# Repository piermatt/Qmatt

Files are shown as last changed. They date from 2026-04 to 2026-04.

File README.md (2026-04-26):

# Low-Cost Arduino-Based ODMR System for NV Centers in Diamond




A fully open-source, low-cost Optically Detected Magnetic Resonance (ODMR)
spectrometer targeting nitrogen-vacancy (NV⁻) centers in diamond, built around
the **Seeeduino XIAO ESP32-C3** microcontroller and the **ADF4351** wideband
PLL synthesizer.

---

## Repository Structure

```
odmr_nv_repo/
├── hardware/
│   ├── schematic/          # KiCad schematic (.kicad_sch, .pdf)
│   ├── gerber/             # PCB Gerber files for fabrication
│   └── 3d_parts/           # STL files for 3-D printed optomechanics
├── software/
│   ├── firmware/           # Arduino (.ino) firmware for ESP32-C3
│   └── analysis/           # Python scripts for data processing & plotting
├── references/             # Key literature (DOI list + BibTeX)
├── results/
│   └── sample_data/        # Example sweep CSV outputs
├── BOM.csv                 # Bill of Materials with estimated costs
└── README.md
```

---

## Operating Principle

1. A **532 nm CW laser** (5 mW) illuminates
   the diamond sample, polarising NV spins into the ms = 0 ground state.
2. Microwave radiation from the **ADF4351** (2850 – 2890 MHz) is swept across
   the NV zero-field splitting (~2870 MHz).
3. At resonance, spin population is transferred to ms = ±1, reducing
   photoluminescence — the **ODMR dip**.
4. A photodiode + **TL082 op-amp** transimpedance/buffer stage converts
   PL intensity to voltage; the ESP32-C3 ADC samples differentially (MW ON vs OFF)
   to extract contrast and reject common-mode noise.

---

## Quick Start

### Hardware
1. Fabricate the PCB from `hardware/gerber/` (e.g. JLCPCB / PCBWay, 2-layer).
2. Assemble components following `hardware/schematic/odmr_schematic.pdf` and `BOM.csv`.
3. Print `hardware/3d_parts/` STL files (PLA, 0.2 mm layer, 20% infill).
4. Mount: laser → ND filter holder → diamond stage → 550 nm longpass filter → photodiode.

## Experimental Setup

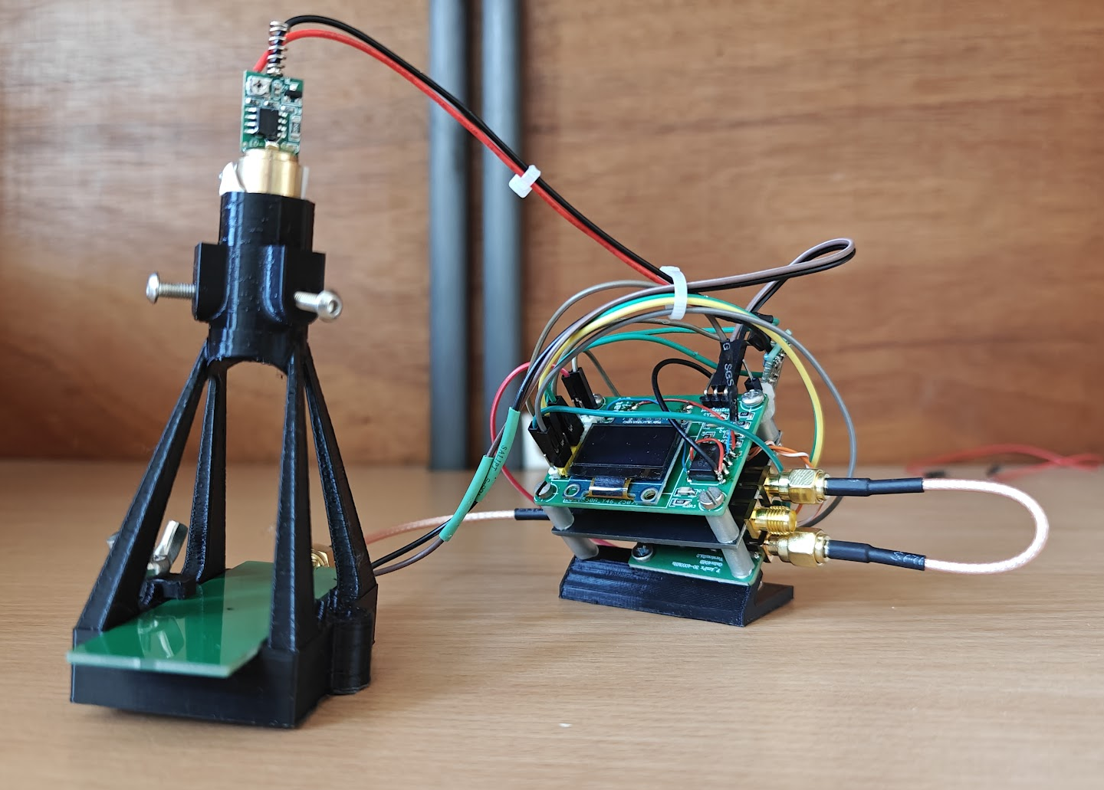
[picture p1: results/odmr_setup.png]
DIY ODMR Setup


Figure: Compact, low-cost ODMR system integrating:
- ADF4351 microwave source
- 0.1-2000MHz Broadband RF Amplifiers
- ESP32-C3 control and acquisition board
- Photodiode detection
- 3D-printed optomechanical mount

The system is designed for alignment simplicity and minimal footprint while maintaining sufficient stability for ODMR measurements.

### Firmware
1. Install **Arduino IDE ≥ 2.x** + ESP32 board support (`esp32` by Espressif, ≥ 3.x).
2. Open `software/firmware/odmr_firmware.ino`.
3. Select board: **XIAO_ESP32C3** — Flash 4 MB, no PSRAM.
4. Upload and open Serial Monitor at **115200 baud**.
5. Send:
   - `S` — full run (survey + differential sweep)
   - `V` — survey scan only
   - `D` — differential ODMR only
   - `X` — abort current scan

## Example ODMR Spectrum

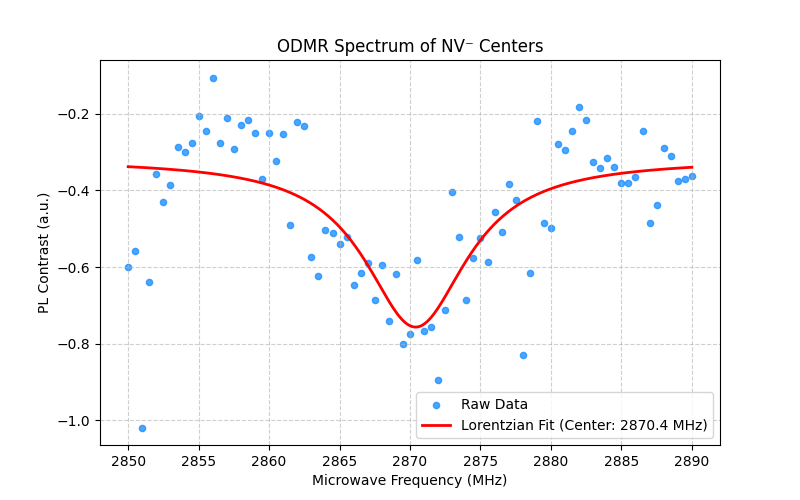
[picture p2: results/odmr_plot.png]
ODMR Spectrum


*Figure: Optically Detected Magnetic Resonance (ODMR) spectrum of NV⁻ centers in diamond.*

A clear fluorescence dip is observed near the zero-field splitting (~2870 MHz), corresponding to the ms = 0 → ms = ±1 transition. The contrast arises from spin-dependent intersystem crossing, which reduces photoluminescence at resonance.

**Key observations:**
- Broad dip centered around **~2870–2872 MHz**, aligning excellently with the theoretical ZFS without significant calibration offset.
- Signal-to-noise is sufficient for low-cost hardware to properly resolve the resonance curve.
- Demonstrates feasibility of differential acquisition using MW ON/OFF modulation.

## Sweep Parameters (default firmware)

| Parameter | Value | Notes |
|---|---|---|
| Frequency start | 2850 MHz | Below NV ZFS |
| Frequency stop | 2890 MHz | Above NV ZFS |
| Step size | 0.5 MHz | 500 kHz resolution |
| Averages / step | 8 ON/OFF pairs| ~50 s total sweep |
| ADC integration | 20 ms | 50 Hz rejection (64-sample window) |
| RF settle time | 5 ms | Safe PLL lock margin |

---

## License

MIT License — see [LICENSE](LICENSE).

## Citation

If you use this system in published work, please cite:

> Mattia Pierpaoli. *Low-Cost Arduino ODMR for NV Centers in Diamond*. GitHub, 2026.
> https://github.com/piermatt/Qmatt

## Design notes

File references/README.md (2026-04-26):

# Key References — DOI List

| # | Authors | Title (short) | Journal / Source | Year | DOI |
|---|---|---|---|---|---|
| 1 | Gruber et al. | ODMR on single NV defect centers | Science | 1997 | 10.1126/science.276.5321.2012 |
| 2 | Doherty et al. | The NV colour centre in diamond (review) | Physics Reports | 2013 | 10.1016/j.physrep.2013.02.001 |
| 3 | Rondin et al. | Magnetometry with NV defects (review) | Rep. Prog. Phys. | 2014 | 10.1088/0034-4885/77/5/056503 |
| 4 | Barry et al. | Sensitivity optimization for NV magnetometry (review) | Rev. Mod. Phys. | 2020 | 10.1103/RevModPhys.92.015004 |
| 5 | Clevenson et al. | Broadband magnetometry with diamond waveguide | Nature Physics | 2015 | 10.1038/nphys3291 |
| 6 | Schloss et al. | Simultaneous broadband vector magnetometry | Phys. Rev. Applied | 2018 | 10.1103/PhysRevApplied.10.034044 |
| 7 | Webb et al. | Nanotesla sensitivity compact NV magnetometer | Appl. Phys. Lett. | 2021 | 10.1063/1.5095241 |
| 8 | Chipaux et al. | Magnetic imaging with NV ensemble | Eur. Phys. J. D | 2015 | 10.1140/epjd/e2015-60080-y |
| 9 | Analog Devices | ADF4351 datasheet | Datasheet | 2021 | analog.com/ADF4351 |
|10 | Seeed Studio | XIAO ESP32-C3 Getting Started | Documentation | 2023 | wiki.seeedstudio.com/XIAO_ESP32C3 |

## Reading Guide

**Start here (foundations):**
- Refs 2 & 3: Complete reviews of NV physics and magnetometry — essential reading.
- Ref 4 (Barry 2020): Definitive guide to sensitivity, noise sources, and ODMR modes.

**Low-cost / practical implementations:**
- Ref 7 (Webb 2021): Compact diamond NV magnetometer — closest to this project's spirit.
- Ref 5 (Clevenson 2015): Light-trapping geometry for sensitivity enhancement.

**Hardware datasheets:**
- Refs 9 & 10: ADF4351 PLL and ESP32-C3 microcontroller.

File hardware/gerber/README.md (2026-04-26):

# Gerber Files — ODMR PCB v1.0

## Ordering (JLCPCB example)
1. Zip all files in this folder → upload to jlcpcb.com
2. Select: 2-layer, FR4, 1.6 mm, HASL, green, qty 5
3. Estimated cost: ~$2 USD per board (min order 5 pcs)

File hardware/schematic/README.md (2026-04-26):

# Schematic

## Design Notes

### Signal Chain
```
532 nm laser  ──(gate: Q1/2N2222A)──►  Diamond sample
                                              │ PL (>550 nm)
                                              ▼
                                        BPW34 photodiode
                                              │ photocurrent
                                              ▼
                                   TL082 U1.1 — transimpedance amp
                                   R_f = 1 MΩ, C_f = 10 pF
                                              │ voltage
                                              ▼
                                   TL082 U1.2 — unity buffer
                                   Virtual GND: R1=R2=1kΩ → VIRTUAL_GND=2.5V
                                              │
                                              ▼
                                   ESP32-C3 ADC (GPIO3, 12-bit, Vref=3.3V)
```

### Microwave Path
```
ADF4351 module
  CLK  → ESP32-C3 GPIO8  (SPI SCK)
  DATA → ESP32-C3 GPIO10 (SPI MOSI)
  LE   → ESP32-C3 GPIO7
  CE   → 3.3 V (always enabled)
  RF_OUT → SMA J2 → coaxial → Cu microwave loop near diamond
```

### Laser Gate
```
ESP32-C3 GPIO2 → 10 kΩ → Q1 base
Q1 collector → laser module VCC (3–5V)
Q1 emitter  → GND
```

### Power
- USB-C 5 V from PC or power bank → XIAO onboard 3.3 V LDO
- ADF4351 module powered from 5 V USB line
- Laser module powered from 5 V through Q1

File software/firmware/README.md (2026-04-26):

# Firmware — odmr_firmware.ino

## Target Platform
- **Board**: Seeeduino XIAO ESP32-C3
- **Arduino IDE**: ≥ 2.x with esp32 board support ≥ 3.x
- **Board package**: `esp32` by Espressif Systems

## Installation
1. In Arduino IDE → Boards Manager → search "esp32" → install Espressif esp32
2. Select: **Tools → Board → XIAO_ESP32C3**
3. Tools → Flash Size: **4MB (No OTA)**
4. Upload `odmr_firmware.ino`

## Serial Commands (115200 baud)
| Command | Action |
|---|---|
| `S` | Survey scan then differential sweep |
| `V` | Survey scan only |
| `D` | Differential sweep only |
| `X` | Abort current scan mid-sweep |

## Output Format — Survey
```
# SURVEY_START
# Freq_MHz, ADC_Sum
2850.00, 87234
2850.50, 87190
...
# SURVEY_END
```

## Output Format — Differential Sweep
```
# ODMR_SWEEP_START
# Freq_MHz, OFF_sum, ON_sum, Contrast_%
2850.00, 698876, 698712, 0.0235
...
# ODMR_SWEEP_END
```

## Tuning Parameters
Edit these `#define` lines in the firmware:

| Define | Default | Description |
|---|---|---|
| `FREQ_START_MHZ` | 2850.0 | Sweep start frequency (MHz)  |
| `FREQ_STOP_MHZ` | 2890.0 | Sweep stop frequency (MHz) |
| `FREQ_STEP_MHZ` | 0.5 | Step size (MHz) |
| `DIFFERENTIAL_AVG` | 8 | ON/OFF averages per step |
| `SETTLE_US` | 5000 | RF settle time (µs) |
| `ADF_POWER` | 3 (+5dBm) | ADF4351 output power 0–3 |

## Dependencies
- Built-in `SPI.h` only — no external libraries required.

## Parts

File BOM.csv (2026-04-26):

# | Reference | Description | Value / Part Number | Quantity | Unit Price (EUR) | Total (EUR) | Supplier / Notes
1 | U_MCU | Microcontroller | Seeeduino XIAO ESP32-C3 | 1 | 5.5 | 5.5 | Seeed Studio / AliExpress
2 | U_PLL | Wideband PLL Synthesizer | ADF4351 module (25 MHz TCXO on-board) | 1 | 8 | 8 | AliExpress (bare module)
3 | U1 | Dual JFET Op-Amp | TL082CP (DIP-8) | 1 | 0.4 | 0.4 | LCSC / Mouser
4 | LD1 | Green DPSS Laser Module | 532 nm / 5 mW CW / 3–5 V TTL gate | 1 | 12 | 12 | AliExpress — verify collimation
5 | PD1 | Photodiode | BPW34 or equivalent Si PIN | 1 | 0.5 | 0.5 | LCSC / Mouser
6 | F1 | Longpass Optical Filter | 550 nm longpass | 1 | 8 | 8 | AliExpress OD4 notch or Thorlabs
7 | ND1 | ND Filter (optional) | ND 0.3–1.0 to protect PD | 1 | 2 | 2 | AliExpress
8 | Q1 | NPN Transistor (laser gate) | 2N2222A or BC337 | 1 | 0.1 | 0.1 | Generic
9 | R1-R2 | Resistor 1 kΩ (virtual GND divider) | 1 kΩ 1% 0.25 W | 2 | 0.02 | 0.04 | Generic
10 | R3 | Transimpedance resistor | 1 MΩ 1% 0.25 W | 1 | 0.05 | 0.05 | Generic
11 | R4 | Base resistor (Q1) | 10 kΩ 0.25 W | 1 | 0.02 | 0.02 | Generic
12 | C1-C2 | Bypass capacitor | 100 nF ceramic 0805 | 2 | 0.05 | 0.1 | Generic
13 | C3 | Bypass capacitor (power) | 10 µF electrolytic | 1 | 0.1 | 0.1 | Generic
14 | C4 | Photodiode feedback cap | 10 pF ceramic (stability) | 1 | 0.05 | 0.05 | Generic
15 | J1 | USB-C connector | On XIAO board (no extra part) | 0 | 0 | 0 | Included
16 | J2 | SMA connector (RF out) | SMA edge-mount female | 1 | 0.8 | 0.8 | AliExpress
17 | J3 | Pin headers | 2.54 mm single row 10-pin | 2 | 0.2 | 0.4 | Generic
18 | PCB | Custom PCB (2-layer) | FR4 / 1.6 mm / HASL / 100×80 mm | 1 | 5 | 5 | JLCPCB (5 pcs min ~25 EUR → per unit)
19 | MISC | Misc (wire AWG28 wires optical table screws) | Assorted | 1 | 2 | 2 | Local
 |  |  |  |  |  | 45.06 | TOTAL ESTIMATED COST (EUR)

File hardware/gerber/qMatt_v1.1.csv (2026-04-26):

No. | Quantity | Comment | Designator | Footprint | Value | Manufacturer Part | Manufacturer | Supplier Part | Supplier
1 | 2 | KH-2.54PH180-2X2P-L11.5 | 3v3,5v | HDR-TH_4P-P2.54-V-M-R2-C2-S2.54 |  | KH-2.54PH180-2X2P-L11.5 | kinghelm(金航标) | C19630931 | LCSC
2 | 3 | 100nF | C1,C2,C4 | C1206 | 100nF | CL31B104KBCNNNC | SAMSUNG(三星) | C24497 | LCSC
3 | 1 | 33pF | C5 | C1206 | 33pF | CGA1206C0G330J102JT | HRE(芯声) | C22374880 | LCSC
4 | 2 | 10uF | C11,C12 | C1206 | 10uF | CL31A106KBHNNNE | SAMSUNG(三星) | C13585 | LCSC
5 | 4 | 100nF | C13,C14,C15,C16 | C1206 | 100nF | 1206B104K101NT | FH(风华) | C110255 | LCSC
6 | 4 | HOLE 3MM | H1,H2,H3,H4 | HOLE_3MM
7 | 1 | BPW34 | pd | SENSOR-TH_BPW34 |  | BPW34 | VISHAY(威世) | C85128 | LCSC
8 | 3 | 1kΩ | R1,R2,R4 | R1206 | 1kΩ | 1206W4F1001T5E | UNI-ROYAL(厚声) | C4410 | LCSC
9 | 1 | 1MΩ | R3 | R1206 | 1MΩ | 1206W4F1004T5E | UNI-ROYAL(厚声) | C17927 | LCSC
10 | 1 | 47kΩ | R7 | R1206 | 47kΩ | 1206W4F4702T5E | UNI-ROYAL(厚声) | C25833 | LCSC
11 | 1 | SEEDUINO_XIAO_ESP32C3 | U1 | SEEDUINO_XIAO_ESP32C3
12 | 1 | TL082AD | U2 | PDIP-8_L10.2-W6.5-P2.54-LS7.6-BL |  | TL082AD | Sungine(双竞集成) | C5274793 | LCSC
13 | 1 | OLED | U4 | OLED
14 | 1 | 2541FV-2x4P | U6 | HDR-TH_8P-P2.54-V-F-R2-C4-S2.54 |  | 2541FV-2x4P | HanElectricity(瀚源) | C18723055 | LCSC

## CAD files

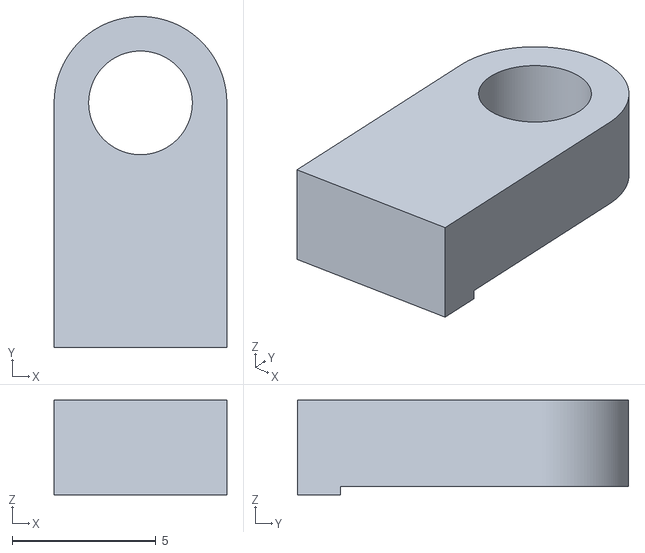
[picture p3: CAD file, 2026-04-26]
hardware/3d_parts/clip.stl
6.00 x 11.5 x 3.30

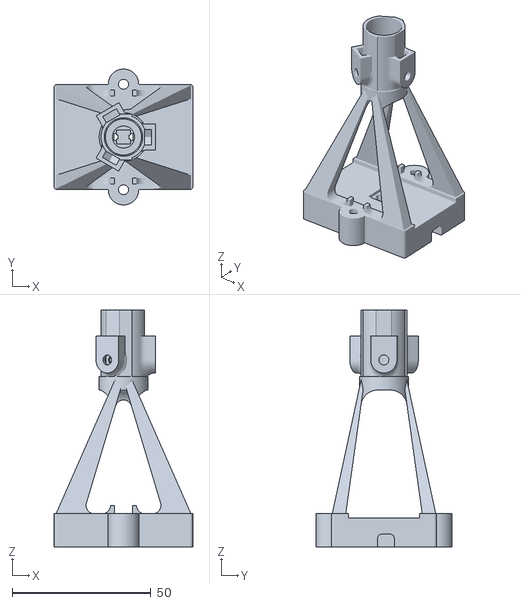
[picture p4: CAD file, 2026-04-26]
hardware/3d_parts/base.stl
50.0 x 49.0 x 85.4

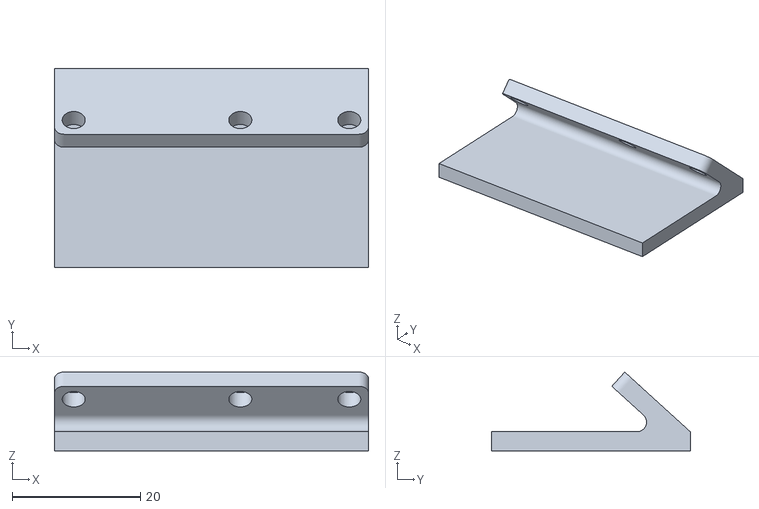
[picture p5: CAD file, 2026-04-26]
hardware/3d_parts/CONTROLLER_V.12.stl
49.0 x 31.0 x 12.3

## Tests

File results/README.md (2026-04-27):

# Results

This folder contains example sweep data and output plots, togheter with chacacterization of the optical filter and laser used

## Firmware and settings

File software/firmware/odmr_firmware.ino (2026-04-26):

/*
 * Noise-Optimized Differential ODMR Firmware
 * Target: Seeeduino XIAO ESP32-C3
 * Repository: https://github.com/piermatt/Qmatt
 * MIT license
 * Author: M. Pierpaoli [Gdansk University of Technology]
 *
 * Pin mapping (ESP32-C3 GPIO):
 *   Laser Gate  : D0 = GPIO 2  (via 2N2222A transistor, active-HIGH)
 *   ADC Signal  : D1 = GPIO 3  (ADC_SIGNAL net → TL082 U1.2 output)
 *   ADF4351 CLK : D8 = GPIO 8  (SPI SCK)
 *   ADF4351 DATA: D10 = GPIO 10 (SPI MOSI)
 *   ADF4351 LE  : D7 = GPIO 7  (Chip select / latch enable)
 *   ADF4351 CE  : tied directly to 3.3 V on board (always enabled)
 *
 * TL082 virtual-ground note:
 *   Op-amp runs on +5 V single supply. R1/R2 (1 kΩ each) create
 *   VIRTUAL_GND at +2.5 V → output idles near mid-rail (~2048 counts).
 *   Contrast is computed differentially (ON vs OFF) → offset cancels.
 *
 * NV⁻ charge-state protection:
 *   1. Survey scan: MW always ON, laser gated per step (short pulses).
 *   2. Main sweep: laser gated OFF between frequency steps.
 *
 * Sweep timing (DIFFERENTIAL_AVG = 8):
 *   Per step: 8 × 2 × (5 ms settle + 20 ms ADC) ≈ 0.4 s → ~33 s total
 */

#include <SPI.h>

// ── Pin definitions ────────────────────────────────────────────────
#define PIN_LASER_GATE   1    // GPIO 2 (D0)
#define PIN_ADC_SIGNAL   3    // GPIO 3 (D1) — ADC channel
#define PIN_ADF_LE       5    // GPIO 7 (D7)

// ── Sweep parameters ──────────────────────────────────────────────
#define FREQ_START_MHZ   2850.0f
#define FREQ_STOP_MHZ    2890.0f
#define FREQ_STEP_MHZ    0.5f
#define DIFFERENTIAL_AVG 8         // ON/OFF pairs per step
#define SETTLE_US        5000      // 5 ms RF-switch settling

// ── ADF4351 parameters ────────────────────────────────────────────
#define ADF_REFIN_MHZ    25.0f
#define ADF_POWER        3         // +5 dBm
#define ADF_MOD          50        // fPFD/MOD = 500 kHz resolution

static uint32_t g_R4 = 0;

// ── SPI helper ────────────────────────────────────────────────────
static void adf_write(uint32_t reg) {
  SPI.beginTransaction(SPISettings(10000000, MSBFIRST, SPI_MODE0));
  digitalWrite(PIN_ADF_LE, LOW);
  SPI.transfer((reg >> 24) & 0xFF);
  SPI.transfer((reg >> 16) & 0xFF);
  SPI.transfer((reg >>  8) & 0xFF);
  SPI.transfer( reg        & 0xFF);
  digitalWrite(PIN_ADF_LE, HIGH);
  delayMicroseconds(2);
  digitalWrite(PIN_ADF_LE, LOW);
  SPI.endTransaction();
}

// ── RF output enable / disable ────────────────────────────────────
static void adf_rf(bool on) {
  if (on) g_R4 |=  (1UL << 5);
  else    g_R4 &= ~(1UL << 5);
  adf_write(g_R4);
}

// ── Program ADF4351 to target frequency ──────────────────────────
static void adf_set_freq(float freq_mhz) {
  const float fPFD = ADF_REFIN_MHZ;
  uint32_t INT  = (uint32_t)(freq_mhz / fPFD);
  uint32_t FRAC = (uint32_t)roundf((freq_mhz / fPFD - INT) * ADF_MOD);
  if (FRAC >= (uint32_t)ADF_MOD) { INT++; FRAC = 0; }

  uint8_t  prescaler = (INT >= 75) ? 1 : 0;
  uint32_t band_sel  = (uint32_t)ceilf(fPFD / 0.125f);
  if (band_sel > 255) band_sel = 255;

  uint32_t R5 = (5UL) | (3UL << 19);
  g_R4 = (4UL) | ((uint32_t)(ADF_POWER & 0x3) << 3) | (1UL << 5) | (1UL << 23);
  uint32_t R3 = (3UL) | (band_sel << 12);
  uint32_t R2 = (2UL) | (1UL << 7) | (7UL << 9) | (1UL << 14)
              | (6UL << 26) | ((uint32_t)prescaler << 27);
  uint32_t R1 = (1UL) | ((uint32_t)ADF_MOD << 3) | (1UL << 15);
  uint32_t R0 = (0UL) | ((FRAC & 0xFFF) << 3) | ((INT & 0xFFFF) << 15);

  adf_write(R5); adf_write(g_R4); adf_write(R3);
  adf_write(R2); adf_write(R1);   adf_write(R0);
}

// ── ADC: 20 ms integration (50 Hz noise rejection) ────────────────
static uint32_t adc_20ms() {
  uint32_t sum = 0;
  for (int i = 0; i < 64; i++) {
    sum += analogRead(PIN_ADC_SIGNAL);
    delayMicroseconds(312);   // 64 × 312 µs ≈ 20 ms
  }
  return sum;
}

static int sweep_steps() {
  return (int)roundf((FREQ_STOP_MHZ - FREQ_START_MHZ) / FREQ_STEP_MHZ) + 1;
}

// ── PASS 1: Survey scan ───────────────────────────────────────────
void run_survey() {
  int steps = sweep_steps();
  Serial.println("# SURVEY_START (MW-ON, laser gated per step)");
  Serial.println("# Freq_MHz, ADC_Sum");
  adf_rf(true);
  for (int i = 0; i < steps; i++) {
    if (Serial.available() && Serial.peek() == 'X') break;
    float freq = FREQ_START_MHZ + i * FREQ_STEP_MHZ;
    adf_set_freq(freq);
    delayMicroseconds(SETTLE_US);
    digitalWrite(PIN_LASER_GATE, HIGH);
    uint32_t val = adc_20ms();
    digitalWrite(PIN_LASER_GATE, LOW);
    Serial.print(freq, 2); Serial.print(", "); Serial.println(val);
  }
  adf_rf(false);
  Serial.println("# SURVEY_END");
}

// ── PASS 2: Differential ODMR sweep ──────────────────────────────
void run_sweep() {
  int steps = sweep_steps();
  Serial.println("# ODMR_SWEEP_START");
  Serial.println("# Freq_MHz, OFF_sum, ON_sum, Contrast_%");
  Serial.println("# Laser warm-up 500 ms...");
  digitalWrite(PIN_LASER_GATE, HIGH); delay(500);
  digitalWrite(PIN_LASER_GATE, LOW);

  for (int i = 0; i < steps; i++) {
    if (Serial.available() && Serial.peek() == 'X') break;
    float freq = FREQ_START_MHZ + i * FREQ_STEP_MHZ;
    adf_set_freq(freq);
    delay(5);

    uint32_t total_off = 0, total_on = 0;
    for (int j = 0; j < DIFFERENTIAL_AVG; j++) {
      adf_rf(false);
      delayMicroseconds(SETTLE_US);
      digitalWrite(PIN_LASER_GATE, HIGH);
      total_off += adc_20ms();
      digitalWrite(PIN_LASER_GATE, LOW);

      adf_rf(true);
      delayMicroseconds(SETTLE_US);
      digitalWrite(PIN_LASER_GATE, HIGH);
      total_on  += adc_20ms();
      digitalWrite(PIN_LASER_GATE, LOW);
    }
    float contrast = (total_off > 0)
      ? ((float)total_off - (float)total_on) / (float)total_off * 100.0f
      : 0.0f;
    Serial.print(freq, 2);   Serial.print(", ");
    Serial.print(total_off); Serial.print(", ");
    Serial.print(total_on);  Serial.print(", ");
    Serial.println(contrast, 4);
  }
  adf_rf(false);
  Serial.println("# ODMR_SWEEP_END");
}

// ── Setup ────────────────────────────────────────────────────────
void setup() {
  Serial.begin(115200);
  while (!Serial) delay(10);
  pinMode(PIN_LASER_GATE, OUTPUT);
  pinMode(PIN_ADF_LE,     OUTPUT);
  digitalWrite(PIN_LASER_GATE, LOW);
  digitalWrite(PIN_ADF_LE, LOW);
  SPI.begin();
  analogReadResolution(12);
  adf_set_freq(FREQ_START_MHZ);
  adf_rf(false);
  Serial.println("# ODMR ready. Commands: S=full  V=survey  D=diff  X=abort");
}

// ── Loop ─────────────────────────────────────────────────────────
void loop() {
  if (!Serial.available()) return;
  char c = Serial.read();
  if      (c == 'S' || c == 's') { run_survey(); run_sweep(); }
  else if (c == 'V' || c == 'v') { run_survey(); }
  else if (c == 'D' || c == 'd') { run_sweep();  }
}
